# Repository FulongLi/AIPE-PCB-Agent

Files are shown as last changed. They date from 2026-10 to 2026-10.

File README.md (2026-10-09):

# AIPE-PCB-Agent

AI-assisted power-electronics PCB engineering with reproducible KiCad automation.

> **AI-GENERATED ENGINEERING PROTOTYPE — V1 — HUMAN REVIEW REQUIRED**

The first benchmark is a 48 V nominal to 24 V, 1 kW synchronous buck converter
with an integrated TMS320F28335 control section. The output current is
approximately 41.7 A. V1 is a review deliverable, not an energisation approval.

## Current status

The V1 converter CAD is complete on `codex/v1-buck-1kw`: 14 schematic sheets,
240 physical items, a fully routed 300 x 220 mm six-layer PCB, and zero native
ERC/DRC findings. Connectivity, source/export hashes and all eleven export
commands are verified. This establishes a CAD review package, not a validated
1 kW converter. See [execution status](docs/status.md) for freeze and GitHub
handoff state.

- [V1 design report](examples/buck-48v-24v-1kw/review/design_report.md)
- [Schematic PDF](examples/buck-48v-24v-1kw/review/schematic.pdf)
- [PCB layer and assembly PDF](examples/buck-48v-24v-1kw/review/pcb_layout.pdf)
- [Board 3D view](examples/buck-48v-24v-1kw/review/pcb_3d.png)
- [Known issues](examples/buck-48v-24v-1kw/verification/known_issues.md)
- [Verification summary](examples/buck-48v-24v-1kw/verification/verification-summary.json)
- [Reproduction instructions](docs/reproduce-v1.md)
- [Frozen V1](examples/buck-48v-24v-1kw/releases/v1/README.md)
- [Portable V1 review archive](examples/buck-48v-24v-1kw/releases/v1-review-package.zip)

## Engineering Knowledge System (V0)

AIPE now learns from manufacturer reference designs. The
[knowledge base](knowledge/README.md) holds traceable, reusable power-electronics
knowledge extracted from TI TIDA-010054 and Wolfspeed CGD15SG00D2,
CGD1700HB2M-UNA and PRD-04814: six engineering Skills (SiC gate drivers,
gate-driver layout, DC-link capacitors, isolated gate bias, sensing, thermal
placement), 13 circuit building blocks, 19 component records and 43
machine-readable rules — each with evidence locations and an explicit
validation status (reference-derived or analytically checked; nothing is
simulated or hardware-validated yet).

```text
python -m automation.knowledge.query "recommended layout practices for an isolated SiC gate driver"
python -m automation.knowledge.validate
```

- [Architecture and reference-learning workflow](docs/knowledge-system.md)
- [V0 status and findings](docs/knowledge-status.md)
- [Retrieval demonstration](knowledge/examples/retrieval-demo.md)

Raw manufacturer files are downloaded to the Git-ignored `.cache/references/`
by `python -m automation.knowledge.acquire`; only original analysis and
metadata are committed.

## Start here

- [Original task](task071026.txt) and [execution constraints](agents/CODEX_V1_TASK.md)
- [Workflow and acceptance gates](docs/agent-workflow.md)
- [Automation architecture](docs/architecture.md)
- [Installation proposal](docs/installation-plan.md)
- [Host environment](docs/environment.md)
- [PCB engineering rules](docs/pcb-design-rules.md) and [knowledge rules](knowledge/rules/engineering_rules.json)
- [Benchmark requirements](examples/buck-48v-24v-1kw/input/requirements.yaml)

## Environment inspection

From the repository root, using an existing Python 3.10 or newer interpreter:

```text
python -m automation.setup.detect_environment --output .aipe/environment.json --markdown docs/environment.md
python -m unittest discover -s tests -v
```

The detector uses the Python standard library and does not install software.
Machine-specific paths belong in ignored `.aipe/local-tools.json`, using
`automation/setup/local-tools.example.json` as a template. Installing software
or dependencies requires the user's confirmation of both software and location.

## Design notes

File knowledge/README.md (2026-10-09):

# AIPE Engineering Knowledge System — V0

> **Reference-derived engineering knowledge — human review required.** Nothing
> here has been simulated or hardware-validated by AIPE. Status labels say
> exactly how far each item has been checked.

This directory holds reusable power-electronics knowledge extracted from
manufacturer reference designs, in a form both engineers and AIPE agents can
use: Markdown for reasoning, JSON for machine use, and evidence pointers for
every claim. The workflow that produces and checks it is described in
[docs/knowledge-system.md](../docs/knowledge-system.md).

## Contents (V0)

| Area | Location | Count |
|---|---|---|
| Reference records, inventories and analyses | [`references/`](references) | 4 references, 25 documents |
| Engineering Skills (Markdown + JSON index) | [`skills/`](skills) | 6 |
| Circuit building blocks | [`circuit_blocks/`](circuit_blocks) | 13 |
| Component knowledge | [`components/`](components) | 19 |
| Engineering rules | [`rules/engineering_rules.json`](rules/engineering_rules.json) | 43 |
| Evidence checks (recomputed calculations, netlist facts) | [`verification/evidence-checks.json`](verification/evidence-checks.json) | 26 |
| JSON schemas | [`schemas/`](schemas) | 6 |
| Retrieval demonstration | [`examples/retrieval-demo.md`](examples/retrieval-demo.md) | 3 questions |

References: TI [TIDA-010054](references/ti/tida-010054/analysis.md) 10 kW DAB ·
Wolfspeed [CGD15SG00D2](references/wolfspeed/cgd15sg00d2/analysis.md) ·
[CGD1700HB2M-UNA](references/wolfspeed/cgd1700hb2m-una/analysis.md) (with PRD-09301) ·
[PRD-04814](references/wolfspeed/prd-04814/analysis.md) gate-bias options.

Skills: [SKILL-001 SiC gate driver](skills/gate_drivers/SKILL-001-sic-gate-driver-design.md) ·
[SKILL-002 gate-driver layout](skills/pcb_layout/SKILL-002-gate-driver-pcb-layout.md) ·
[SKILL-003 DC-link capacitors](skills/capacitors/SKILL-003-dc-link-capacitors.md) ·
[SKILL-004 isolated gate bias](skills/power_electronics/SKILL-004-isolated-gate-bias-supply.md) ·
[SKILL-005 sensing](skills/sensing/SKILL-005-current-voltage-sensing.md) ·
[SKILL-006 thermal placement](skills/thermal/SKILL-006-thermal-placement.md).

## Layout

```text
knowledge/
  references/<vendor>/<design>/
      reference.json    curated record: documents, URLs, revisions, checksums, licence, limitations
      inventory.json    generated metadata of downloaded files (names, sizes, hashes, formats)
      analysis.md       original AIPE analysis of each design decision
  skills/<domain>/SKILL-NNN-*.md|.json
  circuit_blocks/<category>/CB-XX-NNN.json
  components/<category>/CMP-<part>.json
  rules/engineering_rules.json
  verification/evidence-checks.json
  schemas/*.schema.json
  examples/retrieval-demo.md
```

Raw manufacturer files are downloaded to `.cache/references/` (Git-ignored) and
are never committed.

## Vocabulary

**Validation status** (weakest → strongest). V0 contains only the first two.

| Status | Meaning |
|---|---|
| `reference-derived` | Taken from a manufacturer design or document. An implementation exists; it is not independently verified. |
| `analytically-checked` | The cited arithmetic or connectivity was recomputed by `check_evidence` and agrees with the source. |
| `simulation-verified` | Reproduced in AIPE simulation (none yet). |
| `hardware-validated` | Measured on AIPE hardware (none yet). |

**Evidence kinds:** `stated` (written in the source), `observed` (seen in a
BOM, schematic or layout image), `netlist` (confirmed against CAD netlist data),
`calculated` (recomputed), `inferred` (AIPE interpretation the source does not
state — always flagged).

**Rule categories:** `hard-constraint`, `optimization-objective`,
`engineering-recommendation`, `human-review-requirement`. Rule **generality**:
`single-reference-observation`, `multi-source-consistent`,
`manufacturer-guidance`, `physics-derived`. Policies enforced by the validator:

- a single-reference observation is never a hard constraint;
- `multi-source-consistent` needs evidence from at least two references;
- a hard-constraint numerical limit cannot rest on a design-instance value;
- `analytically-checked` requires at least one cited, passing evidence check;
- conflicting approaches are kept in `conflicts`/`alternatives`, not resolved silently.

## Using the knowledge (agents and engineers)

```text
python -m automation.knowledge.query "recommended layout practices for an isolated SiC gate driver"
python -m automation.knowledge.query "DC-link capacitor selection" --type rule --json
python -m automation.knowledge.query --get CB-GD-001
```

Python API for the future AIPE Orchestrator:

```python
from automation.knowledge.query import KnowledgeBase
kb = KnowledgeBase.load()
hits = kb.search("isolated current sensing for an 800 V bus", types={"block"}, limit=5)
block = kb.get(hits[0]["id"])["record"]        # full JSON record
links = kb.related(hits[0]["id"])              # skills, rules, components, referenced_by
```

Each hit carries `id`, `type`, `validation_status`, `path`, `sources` and a
snippet. Agents should cite ids and evidence locations, respect
`applicability` and `exclusions`, and surface `human-review-requirement` rules
to the reviewer instead of deciding them.

## Extending: adding a new reference design

1. Create `references/<vendor>/<design>/reference.json` with document entries
   (official URL, kind, file name/type, `redistribution: not-verified`).
   Use only manufacturer URLs; never construct or guess links.
2. `python -m automation.knowledge.acquire --reference REF-…` — downloads,
   checks file type, records date, size, SHA-256 and resolved URL.
3. `python -m automation.knowledge.inspect_sources` — inventories archives and
   extracts text/CSV into the cache.
4. Read the material; record revision, licence terms, limitations and source
   discrepancies; write `analysis.md` (seven questions per decision).
5. Add or update skills, blocks, components and rules with evidence pointing to
   document ids and locations. Prefer extending existing items over duplicates.
6. Add evidence checks for any calculation or connectivity you rely on
   (`automation/knowledge/check_evidence.py`), then run it.
7. `python -m automation.knowledge.validate` and
   `python -m unittest discover -s tests`; regenerate the retrieval demo with
   `python -m automation.knowledge.query --demo` if rankings change.

## Known limitations of V0

- Four references; sensing and DC-link knowledge rest mainly on TIDA-010054.
- TI Altium sources were not parsed; TI layout knowledge is visual observation.
- Several capacitor and module datasheets could not be retrieved automatically
  (recorded per component as `unverified` or `not-located`).
- Retrieval is lexical BM25 with a small synonym table, adequate for routing an
  agent to the right items but not semantic search.
- No AIPE simulation or hardware validation; Buck V1 is unaffected.

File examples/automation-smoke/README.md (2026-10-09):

# KiCad automation smoke test

This is a passive 10k/10k divider with a three-pin connector. It is not the
1 kW converter. Sources, reports and outputs demonstrate the CAD pipeline only.

The 25 x 18 mm, two-layer board has three components, three nets, routed top and
bottom tracks, a through via and a filled bottom ground zone. All symbol pins
are connected. Official KiCad symbols and footprints are retained locally as
small library subsets. KiCad's installed 3D library supplies the component models.

## Run

1. Configure the existing KiCad CLI/Python in `.aipe/local-tools.json`.
2. Run `automation/kicad_tools/generate_smoke.py` using KiCad's bundled Python.
3. Run `python -m automation.kicad_tools.run_check erc examples/automation-smoke/kicad/AIPE_Smoke.kicad_sch --output examples/automation-smoke/verification`.
4. Run the same wrapper with `drc` and the `.kicad_pcb` source.
5. Run `python -m automation.kicad_tools.export_outputs examples/automation-smoke/kicad/AIPE_Smoke.kicad_pro --output <fresh-output-directory>`.

The checked-in successful exports are under `outputs/`. Export deliberately
requires a fresh directory so stale files cannot establish a passing run.
`python -m automation.verification.verify_smoke` checks the latest reports,
source hashes, exact three-net connectivity and the recorded export hashes.

## Observed result

KiCad 10.0.7 on Windows: ERC zero findings; DRC zero findings, unconnected items
and schematic-parity issues. No checks were disabled by the generator. The
reports list KiCad's default ignored checks explicitly; no exclusions were added.
Schematic PDF, four-page layer PDF, Gerber, drill, BOM, positions, STEP and
front/back/isometric images exported successfully. The final schematic and four
PCB PDF pages were rendered and visually inspected. STEP includes component
models, confirmed by the board renders. The exported netlist matches all seven
expected component-pin connections exactly.

Early failed runs remain in `verification/` as diagnostic history. The
`smoke-result.json` identifies the passing evidence. This test establishes only
this small pipeline, not the correctness of future converter circuitry or layout.

For non-Windows installations provide `AIPE_KICAD_DATA` if the data directory is
not beside the executable at `../share/kicad`, and use an interpreter that can
import the installed KiCad PCB bindings. Those hosts are not tested yet.

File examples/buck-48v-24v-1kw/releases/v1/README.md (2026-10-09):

# Frozen V1 review prototype

AI-GENERATED ENGINEERING PROTOTYPE - V1 - HUMAN REVIEW REQUIRED

Start with review/design_report.md, review/schematic.pdf and review/pcb_layout.pdf.
Read verification/known_issues.md before any physical work. Sources and exported
manufacturing formats are included, but no fabrication order is authorized.

This snapshot must not be overwritten. Future reviewed changes belong in V2.
SHA256SUMS.json covers every file except itself. Original-host absolute paths
inside native command logs are historical evidence; relative content paths
inside this snapshot remain usable. No private host configuration is included.

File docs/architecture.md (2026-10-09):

# Automation architecture

The repository is the engineering record. Each design input, generated CAD
source and verification output must remain traceable to a commit.

```text
Requirements + documented assumptions
    -> engineering calculations and component evidence
    -> deterministic design description
    -> KiCad schematic and PCB source
    -> real KiCad checks and exports
    -> engineering review and frozen V1 package
```

Python is the cross-platform orchestration language. Prefer `kicad-cli` for
checking and exporting; investigate official IPC/Python interfaces for editing.
Where an operation is unavailable, use the documented KiCad file formats and
validate the generated files with KiCad. No third-party MCP server is required.

The initial setup code uses only the Python standard library. Avoid relying on
shell activation, Unix-only locations, or modifying global Python packages.
Discover tool paths using explicit configuration, environment overrides, PATH,
and conventional platform locations. Record which path was actually used.

The CLI check wrapper must preserve nonzero exit codes, capture logs and reject
missing output reports. A unit test using a simulated process result is only a
test of this wrapper; it is not an ERC/DRC result or a CAD integration test.

The complete operation layer will grow with verified needs: project creation,
schematic connectivity and footprint assignment, board stack-up, placement,
tracks/vias/zones, checks, exports and review images. These are planned
capabilities, not a claim of current implementation.

## Engineering knowledge layer

Design decisions can draw on the reference-derived knowledge base in
`knowledge/` (skills, circuit blocks, component knowledge and rules with
evidence and validation status). It is produced and checked by
`automation/knowledge/` and queried through `automation.knowledge.query`. See
[knowledge-system.md](knowledge-system.md). It informs design and review; it
does not replace the KiCad checks above or human engineering review.

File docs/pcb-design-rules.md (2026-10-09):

# Initial PCB engineering review rules

These rules originate in the task. The V1 checker
`automation/verification/check_power_layout.py` now measures the actual routed
board, checks pad/net mapping and power topology, and guards the intended
ground-plane extent. The machine-readable register is
`automation/verification/pcb_rules.json`. Measurements do not constitute
validated electrical or thermal limits. See the example's
`verification/pcb_rule_review.md` for the separate final review and open issues.

| ID | Requirement | Current review method | Required evidence |
| --- | --- | --- | --- |
| PE-PCB-001 | Minimise MOSFET gate loop | human-review | Gate and return path overlay; rationale for topology and geometry |
| PE-PCB-002 | Put high-frequency input capacitors close to half bridge | human-review | Pad-to-pad current path and capacitor placement |
| PE-PCB-003 | Minimise commutation loop | human-review | Complete loop overlay including layer transitions and return |
| PE-PCB-004 | Kelvin routing for current measurement | human-review | Sense pad takeoff and differential path inspection |
| PE-PCB-005 | Keep feedback away from switching node | human-review | All-layer coupling/return-path inspection |
| PE-PCB-006 | Size high-current copper and vias | human-review | Copper dimensions, via plating assumptions, current/loss and thermal rationale |
| PE-PCB-007 | Separate control from noisy power structures | human-review | Functional placement and ground-return review |
| PE-PCB-008 | Place decoupling next to the relevant IC pins | human-review | Per-supply pin map, capacitor location and return path |

The table describes the electrical acceptance evidence, which remains a human
responsibility. The register marks geometric support as semi-automated for
rules 001, 002, 004-008. Only exact pad/net equality, explicit critical topology,
layer count and the ground-plane extent guard are automatic invariants. A short
distance alone does not establish a suitable gate or commutation loop.

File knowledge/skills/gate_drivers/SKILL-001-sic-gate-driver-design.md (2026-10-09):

# SKILL-001 — SiC gate driver design

Status: **reference-derived** (cited calculations analytically checked) · Domain: gate drivers ·
Index: [`SKILL-001-sic-gate-driver-design.json`](SKILL-001-sic-gate-driver-design.json)

## Purpose

Design the circuit between a PWM signal and a SiC MOSFET gate: isolation,
drive strength, gate levels, turn-on/turn-off resistance, off-state immunity,
overcurrent protection and the controller interface. The output is a
schematic-level gate-driver specification that a PCB agent can place and route
with [SKILL-002](../pcb_layout/SKILL-002-gate-driver-pcb-layout.md).

## Applicable conditions

- SiC MOSFETs (discrete or module) in half bridges, full bridges or single-ended stages.
- Bus voltages within the isolation and working-voltage ratings of the chosen driver IC.
- Floating references (high side, or bridges with several references) that need isolated drive.

## Not applicable / out of scope

- Non-isolated low-voltage drivers (e.g. the 48 V Buck V1 benchmark uses a bootstrap half-bridge driver; this skill does not cover that design).
- GaN HEMT gate drive (different gate limits); IGBT-specific short-circuit strategies beyond DESAT basics.
- Choosing the power semiconductor itself (AIPE Transistor Database scope).

## Engineering principles

1. **Isolate every position.** Wolfspeed recommends an isolated driver for every module switch position, including low sides, for safety, removal of noise paths and ground loops, and modularity (PRD-09301 §1.2). TIDA-010054 uses one isolated driver per discrete switch.
2. **Reference the driver to the Kelvin source.** The gate is controlled relative to the source; a dedicated Kelvin source removes common-source inductance from the gate loop (PRD-09301 §1.1). Rule KR-PCB-003.
3. **Gate levels are device-specific.** Keep rails plus tolerance and transients inside the device's absolute maxima (KR-GD-001). For Wolfspeed Gen-3 the guidance is +15 V and −3 to −4 V with ±5 % rails, maxima +19/−8 V (PRD-04814). Negative turn-off is recommended in half bridges but 0 V can be acceptable after evaluation (KR-GD-005, conflict preserved).
4. **Peak current both ways.** Gate current peaks occur at turn-on *and* turn-off; modules with many dies need several amperes (≈6 A in Wolfspeed's CAB006M12GM3 example, PRD-09301 §1.3).
5. **Independent R_G,ON / R_G,OFF.** Tune turn-on for overshoot/EMI and turn-off for loss and immunity (KR-GD-002). Use split OUTH/OUTL drivers (CB-GD-001) or a steering diode (CB-GD-002).
6. **Off-state immunity.** Parasitic turn-on is driven by C_GD·dv/dt into C_GS; mitigations are a higher capacitance-ratio device, negative bias, lower R_G,OFF and an active Miller clamp whose path to the die is short (PRD-06933; KR-GD-003).
7. **Hardware short-circuit protection.** DESAT with HV blocking diode(s), configurable trip and blanking, soft turn-off and a latched fault (CB-GD-001; KR-PR-001, KR-GD-004, KR-GD-011). ADC-based protection is too slow (PRD-09301 §5.1).
8. **Discharge the gate when unpowered.** Gate–source resistor on the device side of R_G (KR-GD-007).
9. **Robust signalling.** Differential/fibre over cables, single-ended conversion close to the IC, RC filters on all signals, hardware interlock as a last barrier (KR-GD-008, KR-GD-009).

## Design procedure

1. Collect device data: V_GS absolute maxima and recommended levels, Q_G at those levels, C_iss/C_rss (capacitance ratio), R_DS(on)(T), short-circuit withstand time, Kelvin-source availability.
2. Choose isolation: working voltage and insulation class at the switch node → driver IC rating (KR-SN-001 applies to every barrier part).
3. Choose gate rails (KR-GD-001, KR-GD-005) and the bias supply with SKILL-004; run the power budget P = Q_G·f_sw·(V_DD−V_EE) (KR-IS-001).
4. Choose driver IC by peak current, split outputs, Miller clamp, DESAT/soft turn-off, UVLO and isolated analog channel needs. Reference instances: UCC21710-Q1 (both TIDA-010054 and CGD1700HB2M-UNA), UCC23514 (CGD15SG00D2, no protection).
5. Select starting R_G,ON/R_G,OFF from device datasheet dv/dt and switching-energy curves (PRD-09301 §3.2 example: 3 Ω on / 1.3 Ω off for a 25 V/ns limit); plan to tune by double-pulse test.
6. Design DESAT: number and rating of HV diodes (≥ device voltage), bias/divider for the trip V_DS at the target current and temperature, blanking capacitor from measured ringing and risk tolerance. Use the CB-GD-001 formulas (checked in EC-001/EC-002).
7. Add gate discharge resistor, rail decoupling sized for Q_G (CGD1700: 20 µF per rail), Miller clamp connection if used.
8. Define the controller interface: interlock wiring, fault/RDY combination and latching, reset timing, signalling standard and filters (CB-GD-003).
9. Record every value as an instance with its basis; hand off placement constraints to SKILL-002.

## Component selection considerations

- Driver IC: isolation (working voltage, surge, CMTI vs. expected dv/dt), peak source/sink current, split outputs, Miller clamp current, DESAT threshold accuracy (UCC21710-Q1 V_OCTH 0.63–0.77 V), soft turn-off current, UVLO levels matched to the chosen rails, propagation delay and skew.
- DESAT diodes: blocking voltage ≥ device rating (or several in series), fast recovery, low capacitance; creepage of the diode bodies to other nets.
- Gate resistors: pulse-rated parts (Wolfspeed uses 2512 pulse-proof resistors); power from Q_G·ΔV·f_sw.
- Steering diodes (if used): fast Schottky, low inductance package.
- Alternatives named in sources only: drivers with integrated flyback controller (ADuM4138, Si828x) for combined bias (PRD-04814).

## PCB constraints (hand-off to SKILL-002)

KR-PCB-001 (gate/Kelvin adjacent layers), KR-PCB-002 (decoupling in the gate loop),
KR-PCB-003 (no KS-to-power-source tie), KR-PCB-005 (driver adjacent to switch),
KR-ISO-001/002/003 (barriers, creepage, net classes), DESAT routing: short drain
connection, compact low-voltage detection side (PRD-09301 §6.4).

## Verification methods

- Calculations: DESAT trip/blanking (EC-001, EC-002), bias power and f_sw limit (EC-003, EC-004), rail set-points (EC-005 … EC-007).
- Netlist checks: gate path, clamp and DESAT connectivity (EC-022, EC-023, EC-026 pattern).
- Measurements: double-pulse test for R_G tuning; off-state V_GS during complementary switching with an optically isolated probe at the device side of R_G (PRD-09301 §6.1–6.2); short-circuit and UVLO fault injection; open-cable/both-inputs-high interlock tests.

## Known limitations

- Values from the references are instance values (TI 2 Ω, 6.4 V/1 µs; Wolfspeed 1 Ω, 6.7 V/46 ns; CGD15SG00D2 10 Ω).
- No AIPE simulation or hardware test underlies this skill; status is reference-derived with checked arithmetic and connectivity.
- Module-level guidance (PRD-09301) is applied to discrete devices only where the physics is the same; module-specific items (multiple gate pins, paralleling) are not expanded here.

## Source references

- TI TIDA-010054 — [analysis](../../references/ti/tida-010054/analysis.md) decisions 4–5.
- Wolfspeed CGD15SG00D2 — [analysis](../../references/wolfspeed/cgd15sg00d2/analysis.md) decisions 1, 2, 6; PRD-06933.
- Wolfspeed CGD1700HB2M-UNA and PRD-09301 — [analysis](../../references/wolfspeed/cgd1700hb2m-una/analysis.md) decisions 1–4.
- Wolfspeed PRD-04814 — [analysis](../../references/wolfspeed/prd-04814/analysis.md) decisions 1, 6.

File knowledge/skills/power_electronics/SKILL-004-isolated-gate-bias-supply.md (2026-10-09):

# SKILL-004 — Isolated gate bias power supply design

Status: **reference-derived** (cited calculations analytically checked) · Domain: power electronics ·
Index: [`SKILL-004-isolated-gate-bias-supply.json`](SKILL-004-isolated-gate-bias-supply.json)

## Purpose

Choose and design the isolated supply that powers each SiC gate driver: topology,
rail generation (+V/−V around the source), power budget, isolation capacitance,
regulation and input protection.

## Applicable conditions

- Isolated SiC gate drivers needing a floating bipolar (or unipolar) supply per reference potential.
- Regulated low-voltage auxiliary input (12 V in all references) or, for some topologies, the HV bus.

## Not applicable / out of scope

- Bootstrap supplies (TIDA-010054 provides an untested bootstrap option only).
- Auxiliary supplies for controllers and logic (non-isolated).

## Engineering principles

1. **Budget the gate power.** P = Q_G · f_sw · (V_DD − V_EE) per device plus quiescent and shared loads must fit the supply rating at the actual input voltage (KR-IS-001). Worked examples: 118 nC, 18 V, 2 W → f_sw ≤ 940 kHz (EC-003); 1330 nC, 19 V, 2 W → 79 kHz, ~70 kHz with margin (EC-004). TI's TIDA-010054 uses an expression with an extra factor 2 (EC-014) — a recorded conflict; the Wolfspeed form follows from charge moved per cycle.
2. **Minimise isolation capacitance.** Common-mode current i = C_iso·dv/dt flows into the control side (KR-IS-003). The CGD15SG00D2 LLC transformer has 0.68 pF typ. inter-winding capacitance; PRD-04814 rates topologies qualitatively (module/LLC/push-pull low; multi-output flyback high).
3. **Block the common-mode path.** A CM choke at the converter input, close to it, with the input capacitor between choke and converter (KR-IS-002).
4. **Generate rails around the source.** Options: dual-output modules, single output + resistor–Zener split, or LDO post-regulation (CB-IS-001/003/004). The Zener split's negative rail is load dependent (CGD15SG00D2 measures −3.3 V with a 3.9 V Zener).
5. **Regulation to the need.** Unregulated module outputs suit most applications; characterisation and non-standard levels need LDOs with ≥0.3 V headroom (KR-IS-005; PRD-06992 §4.3.4). Changing V_DD shifts DESAT blanking when it is biased from V_DD.
6. **Share only with review.** Same-reference low sides may share a supply with decoupling resistors and a combined budget; TI provided but did not test sharing (KR-IS-004).
7. **Protect the auxiliary input** feeding all bias supplies (KR-PR-003; CB-PR-001).

## Design procedure

1. List switch positions and their reference nodes; group positions that share a reference.
2. For each supply compute required power (KR-IS-001) with margin; note input-voltage-dependent ratings (UCC14141-Q1: 1.5 W only at 10.8–13.2 V).
3. Select topology with the PRD-04814 comparison: module (simplest, certified, low C_iso, costlier), single-channel LLC (very low EMI/C_iso, specialised control — UCC25800), push-pull (small transformer, single rail — SN6501/SN6505, LT3999), flyback (flexible, higher C_iso/EMI — ADuM4138, Si828x integrated), multi-output flyback/bridge (lowest cost, hard layout, cross-regulation).
4. Choose rail generation and levels per SKILL-001/KR-GD-001; compute Zener/LDO operating points at min/max load.
5. Add input CM choke and input capacitor; local output decoupling sized for gate charge.
6. Verify isolation rating and creepage of transformer/module against the insulation requirement; estimate i_CM.
7. Define power-good/UVLO interaction with the driver.

## Component selection considerations

- Modules: RECOM R12P21503D (+15/−3 V, 2 W), Murata MGJ2D122005SC (+20/−5 V, 2 W) — only the named alternatives from sources are recorded (Mornsun QA15115R2, MGJ2D series).
- Integrated-transformer IC module: TI UCC14141-Q1 (+15/−4 V configured; RLIM sets current limit).
- Discrete LLC: TI UCC25800-Q1 + Würth 750319177 transformer.
- Post-regulators: Analog Devices LT3082 (positive, 10 µA SET) and LT3015 (negative) on CGD1700HB2M-UNA -R variants.

## PCB constraints

- Each supply inside its driver's isolated island; transformer/module straddles the barrier with required creepage (slots/notches) (KR-ISO-001, KR-ISO-004).
- CM choke and input capacitor order (KR-IS-002); output capacitors within the gate loop (KR-PCB-002).

## Verification methods

- Calculation: power budget (EC-003/EC-004/EC-014), LDO set-points (EC-005…EC-007), LLC frequency (EC-008).
- Measurement: rail regulation versus load and input (Wolfspeed Figure 5 method), ripple during switching, common-mode current/EMI pre-scan.
- Review: isolation coordination of the bias part; sharing configurations.

## Known limitations

- Module datasheets for R12P21503D and MGJ2D122005SC could not be verified automatically; their parameters come from Wolfspeed documents.
- PRD-04814 comparison is qualitative; no efficiency or C_iso numbers per topology.

## Source references

- PRD-04814 [analysis](../../references/wolfspeed/prd-04814/analysis.md); CGD15SG00D2 [analysis](../../references/wolfspeed/cgd15sg00d2/analysis.md) decisions 3–4; CGD1700HB2M-UNA [analysis](../../references/wolfspeed/cgd1700hb2m-una/analysis.md) decision 5; TIDA-010054 [analysis](../../references/ti/tida-010054/analysis.md) decisions 4, 7, 8.

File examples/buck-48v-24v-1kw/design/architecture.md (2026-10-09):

# V1 electrical architecture

The input feeds a 40 A / 70 V bolt-down fuse, local TVS, 14 bulk capacitors and
eight local high-frequency ceramics. Two 100 V MOSFETs form each half-bridge leg.
A 10 uH inductor and four-terminal 2 mohm shunt feed the output capacitor bank
and M5 output terminal. The return bus connects the output and input returns.

The UCC27211 gate driver has independent gate resistors for each MOSFET. Bootstrap
and VDD bypass parts are immediately adjacent to its pins. A latched enable and
logic gates inhibit both PWM paths on reset or fault. A combinational overlap
inhibit supplements, but does not replace, the DSP dead-band generator.

Auxiliary conversion is 48 V -> LM5164 12 V -> TPS54302 5 V -> TPS767D301
1.9 V and 3.3 V. A transistor enables the I/O rail only after core power-good.
Open-drain rail reset signals and a 5 V supervisor hold XRS low. The core output
uses substantial bulk capacitance; early power-down reset timing must be measured.
The LM5164 has its prescribed COT ripple-injection network, not merely an FB divider.

The TMS320F28335PGFA uses a 30 MHz 3.3 V oscillator on XCLKIN, X1 grounded, X2
unconnected, external JTAG pulldown/pullups, flash-boot straps, per-supply-pin
decoupling, ADC reference capacitors and a 22 kohm ADC bias resistor. TEST1 and
TEST2 remain unconnected. Unused analog inputs go to analog ground; unused
digital pins are explicitly marked unused. A 3.3 V UART header exposes SCI-A.

Vin and Vout are divided and buffered. INA240A1 measures inductor current after
the inductor using true Kelvin shunt terminals. LM61 measures power-area PCB
temperature, not MOSFET junction temperature. Separate comparators implement
overcurrent, output overvoltage, overtemperature, and input undervoltage. Faults
clear the hardware enable latch and reach the DSP trip-zone input. Recovery
requires an explicit arm edge after all faults clear.

The analog and digital grounds are one electrical net with placement-controlled
return paths over continuous planes. There is no split under ADC or PWM tracks.
Switch-node copper and plane exposure are restricted to the power area. Sensor
traces avoid the inductor, switching node and gate loops.

Sources, revisions and download hashes are in `../components/references.json`.
The DSP, driver, regulator and sensor implementations use their manufacturer
pin/function tables. Library symbols and custom pin mappings must be checked
against those tables before the schematic milestone is marked complete.

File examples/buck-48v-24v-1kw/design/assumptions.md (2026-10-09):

# V1 design assumptions

AI-GENERATED ENGINEERING PROTOTYPE - V1 - HUMAN REVIEW REQUIRED

The user supplied 48 V nominal input, 24 V output, 1000 W, synchronous buck,
F28335 preferred, and one integrated PCB. The following are engineering choices,
not additional user requirements.

| Topic | V1 assumption and consequence |
|---|---|
| Input | 36-54 V continuous from a current-limited regulated bench supply; no battery reverse-polarity or automotive surge qualification |
| Output | 24 V / 41.667 A continuous design target; positive-current operation; no prebiased-output start or reverse energy acceptance |
| Frequency | 100 kHz, complementary ePWM1A/B, 200 ns initial dead time |
| Environment | 0-50 C ambient; forced airflow and externally supported insulated MOSFET heatsink required |
| Load behavior | 20 A / 100 us illustrative load step; no guaranteed dynamic specification |
| Board | Final 300 x 220 mm, six copper layers, 2.0 mm total; expanded from the initial 300 x 200 mm estimate for placement/routing |
| Copper | L1/L3/L4/L6 70 um finished copper, L2/L5 35 um; PCB vendor must confirm manufacturability and fine-pitch process |
| Power connection | M5 REDCUBE solder terminals, ring lugs, cable strain relief; 2.2 Nm terminal torque only with mechanical support |
| Main inductor | 285 g part requires a separate mechanical clamp/support; solder joints must not carry shock loads |
| Startup | Controlled supply ramp; input-capacitor inrush is not actively limited on this board |
| Software | Hardware design and firmware interface contract; no energized firmware commissioning or validated closed-loop controller in this task |
| Fault protection | Hardware latch inhibits both gates; not a safety-rated function and not a proven hard-short interruption system |
| Development | No purchases, fabrication or physical power-up; full CAD checks plus human review before any later physical work |

The 36-54 V input range is deliberately recorded here because the original task
specified only the nominal voltage. It is not evidence that the board withstands
arbitrary 48 V-bus transients. Transient suppression and measured switch-node
overshoot require review before fabrication.

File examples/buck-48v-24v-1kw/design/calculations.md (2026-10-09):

# V1 calculation record

Generated by `python -m automation.scripts.calculate_buck`.

These are analytical estimates and explicit design scenarios, not measured performance.

## Operating points

Io = Po/Vo = 41.667 A; D = Vo/Vin; fs = 100 kHz; L = 10 uH.
L scenario minimum = 10 uH x 0.8 tolerance x 0.8 droop = 6.4 uH.

| Vin / V | Duty | Ideal Iin / A | Iin at 95% / A | Ripple nominal / App | Ripple scenario / App | Peak scenario / A | Cin RMS / A |
|---|---|---|---|---|---|---|---|
| 36.000 | 0.667 | 27.778 | 29.240 | 8.000 | 12.500 | 47.917 | 19.732 |
| 48.000 | 0.500 | 20.833 | 21.930 | 12.000 | 18.750 | 51.042 | 20.977 |
| 54.000 | 0.444 | 18.519 | 19.493 | 13.333 | 20.833 | 52.083 | 20.863 |

Ripple: dIL = Vo(1-D)/(L fs); ILrms² = Io² + dIL²/12.
Cin RMS² = Io² D(1-D) + D dIL²/12; Cout RMS = dIL/sqrt(12).

## Capacitors

14 x 470 uF / 100 V EKY-101ELL471MM25S: 6580 uF nominal; 5264 uF at -20%; total rating 24.50 Arms at 105 C / 100 kHz. Maximum calculated RMS is 20.98 A, so sharing must remain within approximately 16% of equal sharing. Matched parts, symmetric buses and measured can temperatures are required.
Input capacitive ripple is 0.020 Vpp near D=0.5; ESR/ESL adds to this. Eight 2.2 uF / 100 V X7R parts provide local commutation bypass; no nominal ceramic capacitance is credited in the bulk calculation because bias derating has not been characterized.
4 x 1000 uF / 50 V EKY-500ELL102ML25S: 4000 uF nominal, 3200 uF at -20%, 10.22 Arms rated. Worst scenario ripple: capacitive 0.008 Vpp plus impedance-based proxy 0.130 Vpp. A 20 A load step for 100 us gives 0.625 V capacitive droop plus ESR response.
The manufacturers specify impedance at 100 kHz, not pure ESR. The loss and voltage terms using that impedance are approximations and cannot establish broadband behavior.

## MOSFET and driver

Two CSD19536KCS in parallel per leg, 100 V rated. At 54 V the static voltage margin is 46 V; ringing must be measured and kept below an 80 V engineering target. Individual 4.7 ohm gate resistors and 10 kohm gate-source pulldowns prevent uncontrolled sharing and floating gates.
UCC27211DDAR runs at 12 V. Upper gate-charge budget is 2 x 153 nC per output. Charge/0.5 V requires 0.612 uF effective bootstrap capacitance. Fit 2.2 uF / 25 V plus 100 nF and require at least 1 uF effective. Driver logic inputs are driven at 3.3 V. Initial dead time is 200 ns at each edge; verify both Vgs waveforms before reducing it.
Gate-drive power upper budget is 4 Qg Vg fs. 100 ns total high-side overlap is assumed; gate resistance, parasitics and Miller charge require double-pulse validation. Bootstrap operation requires a low-side refresh interval and does not permit 100% duty.

## Nominal losses

| Item | W |
|---|---|
| mosfet conduction 4 devices | 4.012 |
| high side overlap 100ns total | 10.000 |
| reverse recovery budget | 1.920 |
| output capacitance budget | 1.608 |
| body diode deadtime 200ns each | 1.500 |
| gate drive upper budget | 0.734 |
| inductor copper 100C | 1.946 |
| inductor core budget unverified | 4.000 |
| shunt 2mohm | 3.496 |
| input capacitor ESR proxy | 1.131 |
| output capacitor ESR proxy | 0.075 |
| copper connections budget | 3.000 |
| fuse budget | 0.750 |
| auxiliary input budget | 4.500 |
| Total | 38.674 |

Estimated efficiency 96.28%; if total loss doubles, 92.82%. This is a scenario range, not an efficiency specification.
Reverse-recovery charge of 200 nC per low-side FET and 4 W inductor core loss are explicit budgeting assumptions. They are not guaranteed part parameters. CSD19536KCS Qrr is characterized at a different current; measured losses can exceed the estimate. Coss/Qoss and recovery budget may overlap; conservative accounting is intentional.

## Sensing and thresholds

Vin: 121 kohm / 4.99 kohm divider => 2.139 V at 54 V. Vout: 49.9 kohm / 4.99 kohm => 2.182 V at 24 V. Buffer voltage channels before the ADC sampling capacitors.
2 mohm four-terminal shunt and INA240A1 gain 20 => 1.667 V at full load. Hardware OCP nominal 60.0 A; OVP 27.5 V; LM61 overtemperature 90.0 C. Comparator and reference tolerances, amplifier offset, shunt heating and dynamic delay must be included in test limits.
At 54 V into a short with 6.4 uH, di/dt is 8.44 A/us. The sensing/comparator chain is not certified short-circuit protection: even 3 us adds 25.3 A. The input fuse limits sustained faults, and a current-limited source is an explicit boundary condition. A fuse does not protect the MOSFET from all fast faults.

## Copper and thermal arithmetic

A 100 mm x 25 mm path using two parallel 70 um copper layers at 100 C is 0.638 mohm, dissipating 1.107 W at 41.67 A. This is resistance only, not an IPC temperature-rise qualification.
A 2 mm long 0.5 mm finished-hole via with assumed 25 um barrel plating is 1.137 mohm at 100 C. 32 in parallel dissipate 0.062 W at full load under equal-sharing assumption. Specify plating to the fabricator and avoid using a small signal-via group for the power path.
DSP rail budgeting: 1.9 V x 0.4 A and 3.3 V x 0.2 A. Dual LDO dissipation 1.58 W from 5 V. Auxiliary 12 V rail budget <0.5 A, below the LM5164 1 A rating; a separate fan supply is required.
LC natural frequency is approximately 795.8 Hz. The digital compensator and transient response remain unvalidated; a firmware interface contract is supplied separately.

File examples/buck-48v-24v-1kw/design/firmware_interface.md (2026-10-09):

# Firmware interface contract - hardware V1

This is a required implementation contract, not working or tested firmware.
Hardware CAD completion does not establish stable closed-loop operation.

| Function | DSP / signal | Required interpretation |
|---|---|---|
| High / low PWM | GPIO0 / GPIO1, pins 5 / 6 | ePWM1A / ePWM1B; active high through enable logic |
| Arm | GPIO2, pin 7 | Rising edge latches enable only while FAULT_N is high |
| Hardware trip | GPIO12 / TZ1, pin 21 | FAULT_N low must asynchronously force both PWM outputs low |
| Vin | ADCINA0, pin 42 | Divider factor 4.99 / 125.99; 54 V -> 2.139 V |
| Vout | ADCINA1, pin 41 | Divider factor 1 / 11; 24 V -> 2.182 V |
| Current | ADCINA2, pin 40 | 0.002 ohm x gain 20 = 40 mV/A; positive current only |
| Temperature | ADCINA3, pin 39 | LM61 nominal 0.6 V + 10 mV/C; local PCB temperature |
| Clock | XCLKIN, pin 105 | External 30 MHz; configure PLL only after clock checks |
| Reset | XRS, pin 80 | External open-drain collection; do not drive push-pull high |
| UART | GPIO29 TX pin 2 / GPIO28 RX pin 141 | 3.3 V SCI-A; no RS232 voltage tolerance |

On reset, keep both PWM commands and ARM low, configure TZ1 as a one-shot
asynchronous trip, and leave gate enable cleared. Check rail stability,
reference calibration, plausible sensor values and acceptable input voltage
before arming. Set flash wait states and clock/PLL settings for the actual
silicon and 1.9 V core; use TI's device documentation.

For a 150 MHz time-base clock with no prescaler, center-aligned up/down counting
at 100 kHz uses TBPRD=750. An initial 200 ns dead-band is 30 TBCLK ticks. This is
only an initial timing choice: establish the real switching delays and avoid
cross-conduction across temperature, current and supply. Never rely on the
combinational XOR/AND network to generate deadtime.

Bootstrap supply requires low-side refresh; do not command 100% high-side duty.
Use a conservative duty ceiling (initial software proposal 0.80) and controlled
soft start. Enable synchronous low-side operation only under a reviewed
positive-current strategy; do not force reverse current into an unqualified
input supply. Prebiased-output startup is not supported by this V1 contract.

ADC sample timing should avoid switching edges. Set an acquisition window that
allows the 100 ohm / 1 nF front-end network and DSP sample capacitance to settle.
The ADC full-scale is 3 V. Calibrate offset/gain, especially shunt current and
temperature; rail clamps are not precision 3 V limiters. Implement lower
software current/temperature limits before the hardware fault thresholds.

A voltage-loop plant model, compensator, current limiting, anti-windup,
load-step behavior and stability margins remain to be developed and reviewed.
The approximately 796 Hz nominal LC resonance does not establish a valid
control bandwidth. No gains are invented in this package.

Any fault must keep PWM outputs low and latch a diagnostic. Do not repeatedly
auto-retry a short. Release requires an explicit reviewed restart sequence and
new ARM edge. Verify reset/enable behavior during brownout, loss of 5 V/12 V,
debugger attach, missing clock and firmware hang before any later power tests.

J8 1-2 sets GPIO84 low (SCI-A boot); J8 2-3 or no jumper selects Flash (1111).
Never connect a 5 V UART or a debugger's supply output to these rails. This task
does not authorize physical connection, fabrication or energization.

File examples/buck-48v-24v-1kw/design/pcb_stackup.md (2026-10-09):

# V1 PCB stack-up and assembly basis

AI-GENERATED ENGINEERING PROTOTYPE - V1 - HUMAN REVIEW REQUIRED

Final outline: 300 x 220 mm, rectangular, eight 3.2 mm NPTH support holes,
2.0 mm nominal total thickness. The board is larger than the initial estimate
to accommodate the input ripple-current bank and power/control separation.

| Order | Layer / dielectric | Thickness | Function |
|---|---|---|---|
| 1 | F.Cu | 70 um | Components, gate escapes, VIN/SW/force/output and ground pours |
| | Prepreg | 0.18 mm | FR4 nominal Er 4.3 |
| 2 | In1.Cu | 35 um | Ground, with window beneath extended SW |
| | Core | 0.30 mm | FR4 |
| 3 | In2.Cu | 70 um | VIN and routed signals |
| | Center prepreg | 0.69 mm | FR4 |
| 4 | In3.Cu | 70 um | Routed signals and localized SW power bridge |
| | Core | 0.30 mm | FR4 |
| 5 | In4.Cu | 35 um | Ground, with window beneath extended SW |
| | Prepreg | 0.18 mm | FR4 |
| 6 | B.Cu | 70 um | Power force/output/SW, signals and ground |

Copper totals 0.35 mm and dielectric totals 1.65 mm. ENIG is the proposed
finish. This is a design stack, not a fabricator quotation. The fabricator must
confirm achievable dielectric thicknesses, finished copper, fine-pitch pad
clearance, solder-mask registration and plated-slot quality.

Ordinary signals are 0.2 mm with 0.2 mm clearance. Default vias are 0.6/0.3 mm
diameter/drill. Minimum checks retain 0.15 mm copper clearance/track width,
0.25 mm drilled-hole separation, and 0.5 mm copper-to-edge clearance. Local
power-zone clearance is 0.5 mm. No meaningful DRC category is disabled.

Main copper transfer at each shunt force terminal uses 32 vias, 1.0 mm diameter,
0.5 mm finished drill, 1.5 mm pitch. The analytical barrel estimate assumes
25 um plating and uniform sharing. It is a resistance/loss estimate, not a
certified current rating. At 41.67 A, the two 32-via arrays must be reviewed
with the shunt-pad bottleneck and hot terminal temperature. Main switch-node
copper uses a third 70 um layer to maintain a continuous power connection
through the gate-routing region.

U1/U2 have five grounded exposed-pad vias each; U4 has nine. Vias under exposed
pads require fabrication/assembly agreement on filling, plugging or tenting to
control solder loss. Ground pours connect directly to pads; large through-hole
power joints will need a qualified soldering process and thermal profile.

## Mechanical and assembly review

- L1 uses two plated 8.5 x 3.0 mm slots at 32.51 mm center spacing. This follows
  the 10 uH Figure B lead geometry, not a generic two-pin inductor. Provide a
  clamp/bracket using the support region; do not rely on solder joints for its
  285 g mass. Its upright envelope is about 55 mm tall.
- R9 uses distinct force and sense pads. Do not bridge the sense pads to force
  copper during footprint cleanup. Orient its two sense terminals toward the
  top of the board as shown in the assembly drawing.
- F1 is a 40 A / 70 V MIDI fuse on 30 mm M6 centers. Its PCB pad/hole geometry
  is a proposal; the insulating support, fasteners, torque and replacement
  clearance require a mechanical drawing and fuse-datasheet review.
- J1-J4 are M5 REDCUBE terminals. Support the terminal during tightening and
  restrain the cable. The vendor's 20 C current rating is conditional on the
  complete PCB/cable assembly and cannot be carried unchanged to hot operation.
- Q1/Q2 tabs are VIN; Q3/Q4 tabs are SW. An external common heatsink requires
  insulating pads and shoulder washers with verified thermal and dielectric
  performance. Clearance for the actual heatsink is not proven by the STEP.
- J7 is a TI 14-pin JTAG header; remove pin 6 or use a keyed equivalent. J8
  jumper 1-2 selects SCI boot; 2-3 or open selects Flash. J9 is 3.3 V UART only.
- Custom L1/R9/F1/U1/U2/U4/Y1 3D shapes are dimensioned envelope models, not
  manufacturer-certified mechanical CAD. Slots/threads, exact lead bends,
  clamps, cables, insulation and heatsinks are not fully modeled. Stock
  capacitor models can also differ in exact height from the selected MPN.

See the F.Fab page in pcb_layout.pdf for designators. Test points are identified
in the schematic and the generated test-point map. Mask and paste outputs are
provided for review; no stencil thickness or final reflow process is specified.

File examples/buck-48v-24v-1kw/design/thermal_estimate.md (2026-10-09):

# V1 thermal estimate and limits

The reproducible loss budget is in calculations.json. It combines manufacturer
maximum DC resistance with clearly identified hot-resistance, switching-time,
reverse-recovery, core-loss and interconnect assumptions. It is not a thermal
simulation or measurement.

Use an external heatsink with total sink-to-air thermal resistance no greater
than 1.5 C/W under its specified forced airflow. Budget 0.5 C/W per isolated
TO-220 interface plus the CSD19536KCS maximum 0.4 C/W junction-to-case. Drain
tabs are electrically live: high-side tabs are VIN; low-side tabs are SW. A
common conductive heatsink requires verified insulating pads and shoulder
washers. Heatsink selection and its mechanical drawing remain review items.

With 25 W spread over the four MOSFETs at 50 C ambient, the sink rise would be
37.5 C and an 8 W hottest device would add about 7.2 C junction-to-sink. This
illustrative 95 C junction estimate excludes airflow obstruction and uneven
sharing; doubling the heat invalidates the assumed margin. Do not rate the
converter for continuous 1 kW from this arithmetic alone.

The inductor copper budget uses DCR at 100 C. The 4 W core-loss allocation needs
manufacturer loss data or measurement at the actual waveform. The shunt
dissipates about 3.5 W; its 6 W rating is conditional on terminal temperature.
Give its force terminals substantial copper without compromising Kelvin sense.

The dual LDO loses about 1.58 W for a 400 mA core / 200 mA I/O budget. Its exposed
pad needs a grounded thermal-via matrix and connected copper on multiple layers.
Actual DSP current depends on clocks and enabled peripherals. Confirm regulator
junction temperature and rail transients with the application firmware.

The input capacitor group has limited ripple-sharing margin. Review hot-spot
can temperature and life with the actual airflow. Copper and via resistance
calculations establish loss estimates only; temperature rise, plated slots,
connector joints, fuse studs and narrow necks require a fabricator/engineer review.

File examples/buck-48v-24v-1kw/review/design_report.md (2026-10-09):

# AIPE 48 V to 24 V / 1 kW - V1 design review

**AI-GENERATED ENGINEERING PROTOTYPE - V1 - HUMAN REVIEW REQUIRED**

V1 is a complete CAD review prototype with a routed integrated power/control
board. It is not a fabrication release, a validated converter, or permission to
energize hardware. No parts were purchased and no hardware was powered.

## Specification and assumptions

The supplied benchmark is a synchronous buck, 48 V nominal input, 24 V output,
1000 W and a preferred TMS320F28335 controller. V1 assumes 36-54 V continuous
input from a current-limited regulated bench source, positive output current,
0-50 C ambient, forced airflow and external insulated heatsinking. Prebiased
startup, reverse energy, battery faults, hotplug and automotive transients are
outside the qualified scope. These are engineering choices, not user-supplied
performance guarantees. See [assumptions](../design/assumptions.md).

## Design and calculations

| Quantity | Design value / interpretation |
|---|---|
| Output current | 41.667 A nominal |
| Input current | 21.93 A at 48 V and an assumed 95% efficiency; 29.24 A at 36 V |
| Switching frequency | 100 kHz, complementary PWM with an initial 200 ns deadtime |
| Duty ratio | 0.444-0.667 ideal over the assumed input range |
| Main inductance | 10 uH; 6.4 uH conservative tolerance-plus-droop scenario |
| Inductor ripple | 12 App nominal; 20.83 App in the 54 V / 6.4 uH scenario |
| Peak current | 52.08 A in that scenario, before fault overshoot |
| Input capacitor bank | 14 x 470 uF / 100 V; 6.58 mF nominal; 24.5 Arms summed rating |
| Output capacitor bank | 4 x 1000 uF / 50 V; 4 mF nominal; 10.22 Arms summed rating |
| Input / output ripple demand | 20.98 Arms input; up to 6.01 Arms output |
| Loss budget | 38.67 W nominal scenario; approximately 96.28% calculated efficiency |
| Sensitivity | Doubling the assumed total loss gives approximately 92.82% efficiency |

[Calculations](../design/calculations.md) and their Python generator expose every
assumption. The 100 ns switching-overlap budget, hot MOSFET resistance factor,
reverse recovery, magnetic core loss and copper loss are estimates. Actual gate
and commutation geometry may produce greater loss. No simulated or measured
efficiency, EMI, loop stability or temperature result is claimed.

## Power stage and component selection

The input M5 terminal feeds a 40 A / 70 V MIDI fuse, SMCJ54A TVS, input bulk bank
and eight 2.2 uF / 100 V ceramic bypass capacitors. Two CSD19536KCS MOSFETs are
paralleled in each half-bridge leg, with individual 4.7 ohm gates and 10 kohm
gate-source resistors. Their 100 V rating leaves 46 V static headroom at 54 V;
switching overshoot and the TVS's pulse conditions still require review.

The Vishay IHXL2000VZEB100M3A inductor feeds a Bourns four-terminal 2 mohm shunt
and the output capacitor bank. The magnetic is rated at 83 A for its specified
temperature-rise and 20% inductance-drop conditions. The shunt dissipates about
3.50 W at full load; its 6 W rating depends on terminal temperature. REDCUBE M5
terminals provide bolted connections, with cable strain relief and support
during torque. The 285 g inductor needs an independent clamp.

[Selection and stress register](../components/component_selection.csv),
[purchasing BOM](../components/bom.csv), and
[manufacturer reference hashes](../components/references.json) are separate
from KiCad's native BOM. There are 220 purchased electronic parts plus twelve
bare test points and eight mounting holes. Hardware, heatsinks, insulation,
cables and the magnetic clamp are not a completed mechanical purchasing BOM.

## Driver, control, sensing and protection

The UCC27211 runs from 12 V with local bootstrap/VDD capacitors. LM5164 generates
12 V using the manufacturer's COT ripple-injection arrangement; TPS54302 then
generates 5 V. TPS767D301 supplies approximately 1.899 V core and 3.3 V I/O.
Core power-good enables the I/O regulator through an NPN stage. Open-drain rail
status and a TPS3808 5 V monitor hold the DSP in reset.

All 176 DSP package pins are explicitly assigned. The design includes a 30 MHz
oscillator, per-supply bypass capacitors, ADC reference capacitors and bias
resistor, reset, flash/SCI boot selection, TI 14-pin JTAG and 3.3 V UART.
GPIO0/1 provide ePWM1A/B, GPIO2 arms the latch, and GPIO12 receives FAULT_N/TZ1.
The [firmware interface contract](../design/firmware_interface.md) defines the
required behavior; no commissioned control-loop firmware is supplied.

INA240A1 senses separate shunt Kelvin terminals. Voltage dividers and LM61
temperature sensing feed TLV9004 buffers, ADC RC networks and rail clamps.
The ADC full-scale range is 0-3 V, not 3.3 V. LM61 measures local board
temperature, not MOSFET junction temperature.

LM2903B comparators collect approximately 60 A overcurrent, 27.5 V overvoltage,
90 C board temperature and 34.5 V input undervoltage faults. Fault/reset/12 V
power-good clear the hardware latch; restart requires a new ARM edge. XOR/AND
logic inhibits simultaneous PWM commands, but does not replace DSP deadtime or
prove freedom from propagation-delay hazards. The INA240/comparator path is
not proven fast enough to save MOSFETs during a hard short. At 54 V / 6.4 uH,
short-circuit current can rise about 8.44 A/us.

## PCB implementation

The 300 x 220 x 2.0 mm board has six copper layers. L1/L3/L4/L6 use 70 um copper;
L2/L5 use 35 um ground planes. Power occupies the upper region, driver and
sensing the middle, and DSP/auxiliary supplies the lower region. The layer
order, material assumptions, drill treatment and assembly constraints are in
[stack-up and assembly notes](../design/pcb_stackup.md).

Routing contains 3491 track segments and 720 through vias. VIN uses F.Cu and
In2.Cu; the main switch node uses F.Cu, In3.Cu and B.Cu. The dedicated inner SW
region connects the power copper across interruptions caused by gate routing.
Inductor/shunt/output force paths use both outer layers. Each side of the
surface-mount shunt has 32 large current-transfer vias. Signals use the two
internal signal layers and the back, with top-layer escapes where necessary.
Ground is one electrical net, with two planes and outer copper pours. Plane
windows reduce overlap beneath the extended switch-node region.

## Separate engineering self-review

The review found and corrected an incompatible first package choice for small
logic, undersized driver/regulator exposed-pad geometry, a bootstrap/SW copper
disconnection, duplicate/closely spaced vias, incomplete JTAG routing, exposed-
pad thermal-via omissions, a boot jumper arrangement that could short the rail,
and overlapping connector silkscreen. A separate layer-image inspection found
and corrected a polygon API indexing error that had made a large unintended
ground-plane cutout despite a passing DRC; an area/window invariant now guards
against recurrence. These corrections were followed by new
native checks. Historical failed reports are retained as development evidence.

The final CAD is connected, but its power layout is not optimized or qualified:
driver-to-gate straight-line distances are 8.74-16.17 mm; the LO branch network
has 59.75 mm total track length. HF capacitor-to-drain pad distances are 11 mm
for the upper devices and 16 mm for the lower devices. Switch-node copper is
approximately 508/606/546 mm2 on F.Cu/In3.Cu/B.Cu. These dimensions warrant
overshoot, gate ringing and EMI review. They are not a minimized-loop claim.

The sense paths are true Kelvin nets but are not length-matched differential
pairs. DSP bypass pad distances range up to 6.86 mm. The input bank has only
about 17% summed ripple-rating margin before unequal sharing and temperature.
The [rule-by-rule review](../verification/pcb_rule_review.md) answers all task
review questions and identifies the limits of automated geometry checks.

## Verification and handoff

KiCad 10.0.7 native ERC and DRC, with all severities and schematic parity,
returned zero findings. DRC reports zero unintentionally unrouted connections.
An independently exported XML netlist matches all 645 assigned pins on 85 named
nets; board pads and footprints match the model. All eleven export commands
completed, and export/source hashes are checked. Six automation-wrapper tests
and the original automation smoke example also pass. See
[verification summary](../verification/verification-summary.json).

The review directory contains schematic/layout PDFs and three board views.
Manufacturing contains six copper Gerbers, masks/paste, silkscreen, outline,
drills, coordinates, BOM and STEP. They are review artifacts, not a released
fabrication order. V1 is frozen with a SHA-256 manifest; it must not be edited
for V2. GitHub upload requires repository write access for the authenticated
account; local completion does not imply a remote branch or PR exists.

Priority human decisions are the switching-loop quality, short-circuit strategy,
thermal/mechanical design, input inrush/ripple life, auxiliary rail sequencing
and closed-loop firmware. Read [known issues](../verification/known_issues.md)
before approving any physical work.

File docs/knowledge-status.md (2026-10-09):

# Engineering Knowledge System V0 — execution status

Recorded 2026-10-09. Branch: `feat/engineering-knowledge-v0`. Host: macOS,
Python 3.9.6 (standard library; no packages installed).

| Milestone | State | Evidence |
|---|---|---|
| Repository inspection, branch | Complete | Existing architecture preserved; new code under `automation/knowledge/`, data under `knowledge/` |
| Reference acquisition | Complete | 25 documents (58.5 MB) from ti.com and wolfspeed.com, all `downloaded` with SHA-256; 13 component datasheets downloaded |
| PRD-04814 located | Complete | Linked from official CGD15SG00D2 and CGD1700HB2M-UNA product pages |
| Inspection | Complete | Archive inventories; PDF text; XLSX→CSV; Allegro netlist (86 nets) and ODB++ connectivity parsed |
| Reference analyses | Complete for V0 | 4 `analysis.md` files, 31 decisions answered with the seven questions |
| Skills | Complete | SKILL-001…006, Markdown + JSON, all `reference-derived` |
| Circuit blocks | Complete | 13 blocks: 7 `analytically-checked`, 6 `reference-derived` |
| Components | Complete | 19 records; datasheet URL status 12 verified-pdf, 3 unverified, 4 not-located |
| Rules | Complete | 43 rules: 11 hard constraints, 2 optimisation objectives, 25 recommendations, 5 human-review; 7 single-reference observations (none hard); conflicts preserved in KR-GD-003/004/005, KR-IS-001 |
| Evidence checks | Passed | 26 checks: 24 pass, 2 computed-for-review, 0 fail (5 netlist checks need the local cache) |
| Validation | Passed | `python -m automation.knowledge.validate`: 0 errors; all 19 part numbers found in the manufacturers' own files |
| Tests | Passed | `python -m unittest discover -s tests`: 41 tests OK (6 existing + 35 new); without the cache: 41 OK, 1 skipped |
| Retrieval demo | Complete | `knowledge/examples/retrieval-demo.md` |
| Buck V1 | Unchanged | Frozen manifest hashes verified by test; no diff against `main` under `examples/buck-48v-24v-1kw` |

## Findings worth human attention

- **Gate-power expression conflict:** TI TIDUES0 Eq.30 uses 2·(V_DD−V_EE)·Q_G·f_s;
  Wolfspeed uses Q_G·f_s·ΔV. Recorded in KR-IS-001 (EC-014).
- **DESAT blanking philosophies differ by >5×** (TI 1 µs vs Wolfspeed ≈46 ns
  + 120 ns deglitch). Recorded in KR-GD-004.
- **TMCS1133:** TI's BOM orderable `TMCS1133B1QDVGR` is not in the current
  datasheet (which lists `TMCS1133B1AQDVGR`), and TI's guide states 1100 VDC
  working voltage versus 1343 VDC reinforced in the 2026 datasheet.
- **Source inconsistencies** are listed per reference (`source_discrepancies`),
  e.g. stale UCC21530 text in TIDUES0F, J15 supply conflict, CGD1700 schematic
  vs 2025 BOM values, PRD-04814 stray paragraph.

## Not done / limitations

- TI Altium binaries not parsed; TI layout knowledge is visual.
- No simulation or hardware validation; nothing is above `analytically-checked`.
- Retrieval is lexical (BM25), not semantic.
- Full AIPE Orchestrator not implemented (only the retrieval API it will call).

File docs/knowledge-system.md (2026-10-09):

# Engineering Knowledge System — architecture and workflow

The knowledge system turns manufacturer reference designs into traceable,
reusable design knowledge for AIPE agents. It sits beside the existing CAD
automation and does not change it:

```text
Requirements ──► calculations ──► schematic/PCB generation ──► KiCad checks ──► review
                       ▲                     ▲                       ▲
                       └──── knowledge/ (skills, blocks, components, rules) ──┘
                                   ▲
              automation/knowledge (acquire → inspect → extract → check → store)
```

## Reference-learning pipeline

```text
Reference discovery      manufacturer product pages → curated reference.json
        ↓
Download                 acquire.py: official URLs only, type check, SHA-256, date, resolved URL
        ↓
Document / CAD inspection inspect_sources.py: safe unzip, format inventory, PDF text, XLSX→CSV;
                         allegro_netlist.py / odb_netlist.py for CAD connectivity
        ↓
Engineering extraction   analysis.md per reference (what/why/problem/applicability/evidence/reuse/verification)
        ↓
Skill / rule / component skills/, circuit_blocks/, components/, rules/ with evidence pointers
extraction
        ↓
Evidence validation      check_evidence.py (recompute calculations, confirm netlist facts)
                         validate.py (schemas, cross-refs, traceability, policies, part numbers)
        ↓
Knowledge storage        Git: original analysis + metadata; .cache/references: raw files (ignored)
        ↓
Retrieval                query.py: BM25 search, get, related; JSON for agents
```

| Stage | Command | Output | Committed? |
|---|---|---|---|
| Download | `python -m automation.knowledge.acquire` | `.cache/references/<ref>/…`, acquisition block per document and datasheet | metadata only |
| Inspect | `python -m automation.knowledge.inspect_sources` | `inventory.json`; cache `extracted/`, `text/` | inventory only |
| Check | `python -m automation.knowledge.check_evidence` | `knowledge/verification/evidence-checks.json` | yes |
| Validate | `python -m automation.knowledge.validate` | report (exit 1 on any error) | no |
| Retrieve | `python -m automation.knowledge.query …` | ranked hits / JSON | demo file only |

Every reference document records: source URL, document revision and the basis
for that revision, download date, file type, download status, size and
SHA-256, extraction status and method, redistribution status and limitations.
A failed download is recorded as `failed` with the error; it is never shown as
acquired. Checks that need cached files report `skipped` when the cache is
missing — never `pass`.

## Licensing and redistribution

TI design files are bundled with TI's Important Notice, which permits use only
for developing applications with the TI products and prohibits other
reproduction. Wolfspeed documents are "All rights reserved" without a
redistribution licence. Therefore only original AIPE analysis, derived
knowledge, file inventories, checksums and links are committed. The tests
fail if PDF, ZIP, XLSX, STEP or CAD source files appear under `knowledge/`.

## Environment

Standard-library Python (tested here with Python 3.9.6 on macOS; the existing
automation targets 3.10+). Optional, used only when present: `pypdf` for PDF
text, otherwise macOS PDFKit through `osascript`, otherwise documents are marked
for manual reading. `jsonschema` is used only by a cross-check test. No package
was installed for this work.

## Integration points

- **AIPE Orchestrator (future):** `KnowledgeBase.load()`, `.search()`, `.get()`,
  `.related()` in `automation/knowledge/query.py`; or the CLI with `--json`.
  The Orchestrator is not implemented in V0.
- **Existing PCB review rules:** knowledge rules link to `PE-PCB-001…008`
  (`docs/pcb-design-rules.md`) through `related.project_rules`; the validator
  rejects unknown project rule ids. Several rules carry an `aipe_hook` naming
  the automated check they could become (e.g. net-class clearances, Kelvin-net
  separation).
- **Component databases:** component records are design knowledge, not a
  parametric catalogue. `external_refs.aipe_component_db` and
  `external_refs.aipe_transistor_db` are the join keys for the existing AIPE
  databases (null until linked). Power semiconductors (e.g. C3M0075120K) are
  deliberately not duplicated; they appear only as reference usage.

## Validation status of this V0

See [knowledge-status.md](knowledge-status.md) for the recorded results.

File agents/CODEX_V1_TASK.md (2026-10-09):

# V1 execution contract

The user authorised execution of [task071026.txt](../task071026.txt) on
2026-10-09 (Asia/Shanghai), with the following overriding constraint:

> Confirm required software and its installation location with the user before installing.

This includes additional Python packages and automation dependencies. Existing
software may be used. KiCad 10.0.7 x64 and its official libraries are approved for
`D:\EngineeringTools\KiCad\10.0` by the user's subsequent "可以" reply. No other
package installation or dependency upgrade is authorised. Capture approvals in
the installation plan.

Work in `FulongLi/AIPE-PCB-Agent`, branch `codex/v1-buck-1kw`; preserve existing
content. Do not fork or create another repository to bypass missing write access.
The initial remote commit is `c08c1494f5ea9def80efa3f1cbfaac64defdba4a`.

The original task defines scope and outputs. Progress is tracked in
`docs/status.md`. Missing tools and permission failures must be described as
blockers, never reported as successful verification.

Complete a real KiCad smoke test before converter engineering. Do not disable
meaningful ERC/DRC checks. Do not manufacture or energise hardware. Stop the
design sequence after a frozen V1 ready for human review; V2 needs feedback.

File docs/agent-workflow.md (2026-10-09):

# Workflow and acceptance gates

## 0. Environment and smoke test

Inspect host and repository without overwriting collaborator work. Confirm
software and installation paths before installing. Discover and record the real
KiCad executables. Then generate a small, disposable, fully connected test
circuit and board using the automation layer.

Acceptance requires actual KiCad parsing, ERC, DRC (including unrouted items and
schematic parity), schematic PDF, board PDF, Gerber and drill exports. Record
commands, versions, exit codes and nonempty artifacts. Fix issues and rerun.
Library checks must use the installed or project-local symbol/footprint tables.
The converter work remains gated until this succeeds.

## 1. Requirements and engineering

Translate the task into explicit SI-unit inputs and a separate assumption
register. Unspecified limits must not masquerade as user requirements.
Resolve input range, operating temperature/cooling, ripple and transient targets,
mechanical constraints, manufacturing capabilities and control/firmware scope.
Use documented engineering judgement for routine decisions.

Produce reproducible calculations, component stress/loss estimates, protection
thresholds, thermal assumptions and manufacturer references. Document uncertainty
instead of substituting invented ratings or untested operating claims.

## 2. Schematic and board

Complete power, auxiliary supply, DSP, sensing, protection, clock, reset and
debug circuitry. Assign verified footprints, run ERC and correct violations.
Define a justified stack-up; place, route and inspect all intended connections.
Run DRC, schematic parity, footprint and connectivity checks. Treat CAD errors
as release blockers. Document any warning disposition individually.

## 3. Engineering review and release

Apply `pcb-design-rules.md` independently of CAD checks. Each rule needs evidence
and a truthful result: pass, fail, unverified or not applicable with justification.
Unverified engineering constraints must remain visible to the human reviewer.

Export the required manufacturing files and review package. Check the rendered
schematic and board views, reconcile BOM and placement files, then freeze V1
under `examples/buck-48v-24v-1kw/releases/v1/` with a file/hash manifest.
Never call a partial board a completed V1. Never rewrite a frozen V1 later.

Commit meaningful checkpoints and push to the existing remote when authorised
credentials permit. Open the requested PR only when its actual status can be
described accurately. No physical power-up and no V2 without human feedback.

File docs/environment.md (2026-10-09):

# Host environment

Observed (UTC): 2026-10-09T03:20:14.295780+00:00

This report is generated by `automation.setup.detect_environment`.
It inspects the host and does not install software.

| Item | Observation |
| --- | --- |
| Operating system | Windows 10.0.26300 |
| Architecture | AMD64 |
| CPU | Intel64 Family 6 Model 183 Stepping 1, GenuineIntel |
| Python | 3.10.11 |
| Workspace writable | True |
| PATH entries inspected | 29 |
| git | git version 2.53.0.windows.2 |
| gh | gh version 2.88.1 (2026-03-12) https://github.com/cli/cli/releases/tag/v2.88.1 |
| winget | v1.29.380 |
| choco | not found |
| scoop | not found |
| KiCad CLI | D:\EngineeringTools\KiCad\10.0\bin\kicad-cli.exe |
| KiCad Python | D:\EngineeringTools\KiCad\10.0\bin\python.exe |
| KiCad IPC | unverified; no running API connection tested |

## Inspection boundaries

Local executable paths are retained in ignored `.aipe/environment.json`.
A custom KiCad location must be supplied in `.aipe/local-tools.json` or
`AIPE_KICAD_CLI`; discovery is not a scan of every disk.

KiCad plugin directories observed: 1.
MCP inspection records only explicitly declared names, not credentials or
remote plugin-managed servers. The project does not require a KiCad MCP.

```json
{
  "codex_declared_server_names": [
    "cua_repl"
  ],
  "scope": "Local declarations only; does not establish live server availability"
}
```

Actual KiCad file parsing, ERC, DRC, exports and IPC remain unverified until
the integration smoke test has run. Software installation is subject to the
user's separate confirmation of software and directory.

## KiCad version probe

```json
{
  "returncode": 0,
  "output": "10.0.7"
}
```

## KiCad Python probe

```json
{
  "returncode": 0,
  "output": "3.11.5 (main, Aug 30 2026, 05:41:23) [MSC v.1951 64 bit (AMD64)]\n10.0.7"
}
```

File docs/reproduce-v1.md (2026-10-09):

# Reproducing and checking V1

Use Python 3.10+ for standard-library automation and KiCad 10.0.7 with its
`pcbnew` Python environment and NumPy for board generation/routing. No external
autorouter, MCP service, mouse automation or cloud CAD service is required.
The Windows installation and exact detected paths are documented in
environment.md. On macOS, configure paths to the corresponding installed
KiCad CLI/Python environment; generation has not been executed there.

Machine paths are read from `.aipe/local-tools.json`, explicit environment
configuration or the discovery search. A future install still requires user
approval of software and location. Do not include personal tool paths in Git.

## Inspect without changing the frozen release

Open `examples/buck-48v-24v-1kw/kicad/AIPE_Buck_1kW.kicad_pro` in KiCad.
Symbols, footprint tables, custom footprints and envelope models are project
relative. Standard 3D models use the installed KiCad 10 model directory.
Frozen STEP and review renders do not require those model files to view.

From the repository root:

```text
python -m unittest discover -s tests -v
python -m automation.verification.verify_smoke
python -m automation.verification.verify_buck
```

The converter verifier requires source/dependency hashes, native zero-finding
reports, XML netlist equivalence, six copper Gerbers, export file hashes and a
STEP log without missing-model messages. It does not qualify electrical or
thermal performance. Paths recorded in historical command logs describe the
original host; the verifier resolves source and output paths relative to the
repository.

## Regenerate development sources

These operations replace generated development files. Preserve manual edits
first and do not target `releases/v1`. Run board scripts with the KiCad Python
executable rather than a Python interpreter that cannot import pcbnew.

```text
python -m automation.scripts.calculate_buck
python -m automation.kicad_tools.generate_buck_schematic
python -m automation.scripts.component_records
<kicad-python> automation/kicad_tools/generate_buck_board.py
<kicad-python> automation/kicad_tools/route_buck.py
python -m automation.kicad_tools.run_check erc examples/buck-48v-24v-1kw/kicad/AIPE_Buck_1kW.kicad_sch --output examples/buck-48v-24v-1kw/verification
python -m automation.kicad_tools.run_check drc examples/buck-48v-24v-1kw/kicad/AIPE_Buck_1kW.kicad_pcb --output examples/buck-48v-24v-1kw/verification
<kicad-python> automation/verification/check_power_layout.py
```

Use `export_outputs` with a **fresh output directory**, then assemble the review
package after placing the verified export under manufacturing. Required layer
list: `F.Cu,In1.Cu,In2.Cu,In3.Cu,In4.Cu,B.Cu,F.SilkS,B.SilkS,F.Fab,Edge.Cuts`.
Pass `--pdf-scale 0.9` for this A3 board drawing so it clears the title block.
The exporter adds paste and mask layers and records every command and hash.

The current router uses a 0.25 mm grid, conservative obstacle expansion,
alternating DSP fanout, dedicated gate routing, internal signal routing and
explicit power copper. Geometric proposal generation is followed by official
KiCad zone fill and native checks. UUIDs and route details can vary across
KiCad/library versions, so byte-for-byte reproduction on another version is
not promised. Never reuse an older passing report after editing a child sheet,
footprint, project rule, model or board.

No control-loop firmware is generated. Review the hardware/firmware contract
before writing or running any later converter software.

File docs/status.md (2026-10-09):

# Execution status

Recorded 2026-10-09, Asia/Shanghai. Branch: `codex/v1-buck-1kw`.

| Milestone | State | Evidence |
|---|---|---|
| Preserve existing repository | Complete | Original README and c08c149 history retained |
| Environment and approved installation | Complete | KiCad 10.0.7 x64 at D:/EngineeringTools/KiCad/10.0 |
| Reusable automation smoke | Passed | Real ERC/DRC, netlist and eleven exports |
| Calculations and component records | Complete for V1 review | Explicit assumptions; real MPN BOM and stress register; sourcing limitations recorded |
| Schematic | Complete | Fourteen sheets, 240 physical items, all 176 DSP pins mapped |
| Placement and routing | Complete | Six layers, 300 x 220 mm, 3491 segments, 720 vias |
| Native verification | Passed | Final ERC/DRC zero findings; zero unrouted or schematic-parity findings |
| Netlist and artifact checks | Passed | 645 assigned pins, 85 named nets; board/source/export hashes |
| Engineering and visual review | Complete for V1 review | Ground-plane cutout fixed after image review; open electrical/thermal issues explicitly listed |
| Manufacturing and review outputs | Complete | Gerber, drill, BOM, placement, STEP, fourteen-page schematic and eight-page PCB PDFs, three renders |
| Frozen V1 | Complete locally | 155 files under releases/v1, SHA-256 manifest, plus v1-review-package.zip; source commit 7565481 |
| GitHub push / PR | Blocked by repository permissions | Actual push rejected with HTTP 403; authenticated MrCoconut616: pull=true, push=false; prepared body in v1-pull-request.md |

The next phase is human power-electronics review. No hardware qualification,
fabrication, purchase, physical power-up or V2 redesign was performed.

## Remaining external action

Grant the authenticated account write access to `FulongLi/AIPE-PCB-Agent`, or
provide an already authorized repository authentication context. This is a
GitHub repository permission blocker, not a software-installation request.
No separate repository or unauthorized fork was created.

The completed release was committed as `0e70560`. Running
`git push -u origin codex/v1-buck-1kw` returned:

```text
remote: Permission to FulongLi/AIPE-PCB-Agent.git denied to MrCoconut616.
fatal: unable to access 'https://github.com/FulongLi/AIPE-PCB-Agent.git/': The requested URL returned error: 403
```

No remote branch or pull request was created. Once access is granted, push the
existing branch and open the PR against `main` using `docs/v1-pull-request.md`.
The frozen manifest, disk files, Git blobs and portable ZIP were checked for
byte consistency. Its KiCad default display-state file is retained in Git to
match the immutable snapshot; it contains no credentials or host paths.

## Validation scope

Six automation tests pass. Native checks use the real KiCad 10.0.7 tools with
all severities and schematic parity enabled. Ground-plane extent, component
count, pad-net mapping and critical power/control connections have executable
checks. Gate-loop, EMI, thermal, fault-response and control-loop adequacy still
need engineering review. Windows execution is proven here; macOS/Linux tool
discovery paths are implemented but were not executed on those operating systems.

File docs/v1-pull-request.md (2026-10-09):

# AI-generated 48V to 24V 1kW Synchronous Buck - V1

This adds the first complete integrated power/DSP CAD benchmark: a 48 V nominal
to 24 V / 1 kW synchronous buck using TMS320F28335, documented 36-54 V bench-input
assumptions, real component selection, fourteen schematic sheets and a fully
routed six-layer 300 x 220 mm board. Deterministic Python/KiCad automation,
manufacturer references, calculations, review PDFs/renders and manufacturing
formats are included with a frozen V1 checksum manifest.

Validation: KiCad 10.0.7 ERC/DRC with all severities and schematic parity return
zero findings and no unrouted connections. The exported netlist matches 645
assigned pins on 85 named nets; all 240 physical items have matched footprints
and net assignments. All eleven exports and their hashes pass verification.
Six wrapper tests and the real smoke example pass. Layer-image review also
found and fixed a ground-plane geometry problem that DRC alone did not catch.

**AI-GENERATED ENGINEERING PROTOTYPE - V1 - HUMAN REVIEW REQUIRED.** The package
does not establish fabrication/energization readiness. Review priorities are
gate/commutation geometry, hard-short trip delay, input-capacitor ripple/inrush,
thermal and mechanical assembly, rail sequencing, and the as-yet unvalidated
firmware/control loop. See `review/design_report.md` and
`verification/known_issues.md` in the example. No V2 or physical power-up is
part of this PR.

Target: `codex/v1-buck-1kw` -> `main` in `FulongLi/AIPE-PCB-Agent`.
This file is the prepared PR body; it is not evidence that a remote PR exists.

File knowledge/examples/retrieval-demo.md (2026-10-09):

# Knowledge retrieval demonstration

Generated by `python -m automation.knowledge.query --demo`. Deterministic: rerunning on an
unchanged knowledge base reproduces this file. Scores are BM25 relevance, not confidence.

## What are the recommended layout practices for an isolated SiC gate driver?

| Rank | Id | Type | Title | Status | Score |
|---|---|---|---|---|---|
| 1 | `SKILL-002` | skill | Gate driver PCB layout | reference-derived | 20.121 |
| 2 | `SKILL-001` | skill | SiC gate driver design | reference-derived | 17.56 |
| 3 | `KR-PCB-003` | rule | Never tie the device Kelvin source to the power source in the layout | reference-derived | 14.779 |
| 4 | `KR-GD-007` | rule | Gate-source discharge resistor on the device side of R_G | analytically-checked | 12.121 |
| 5 | `KR-PCB-002` | rule | Gate-driver decoupling inside the gate loop | reference-derived | 11.535 |
| 6 | `KR-IS-004` | rule | Sharing a gate-bias supply requires review | reference-derived | 11.39 |

## What should be considered when selecting DC-link capacitors?

| Rank | Id | Type | Title | Status | Score |
|---|---|---|---|---|---|
| 1 | `SKILL-003` | skill | DC-link capacitor selection and placement | reference-derived | 15.672 |
| 2 | `REF-TI-TIDA-010054` | reference | TIDA-010054 bidirectional dual-active-bridge reference design for level 3 EV charging stations | reference-derived | 7.98 |
| 3 | `KR-CAP-002` | rule | DC-link RMS ripple current within rating at frequency and temperature | reference-derived | 6.985 |
| 4 | `KR-CAP-001` | rule | DC-link capacitance from worst-case ripple charge | analytically-checked | 6.527 |
| 5 | `CMP-B32716H8306K000` | component | TDK (EPCOS) B32716H8306K000 | - | 6.006 |
| 6 | `CMP-B32716H1156K000` | component | TDK (EPCOS) B32716H1156K000 | - | 5.913 |

## What reusable current-sensing circuits are available for a high-voltage converter?

Filter: types = ['block']

| Rank | Id | Type | Title | Status | Score |
|---|---|---|---|---|---|
| 1 | `CB-SN-003` | block | Isolated shunt current sensing (isolated amplifier or delta-sigma modulator) | analytically-checked | 6.292 |
| 2 | `CB-SN-001` | block | Isolated HV bus voltage sensing with resistor ladder and isolated amplifier | analytically-checked | 5.327 |
| 3 | `CB-SN-002` | block | Isolated HV voltage sensing with delta-sigma modulator and MCU SDFM | analytically-checked | 4.587 |
| 4 | `CB-SN-004` | block | Hall-effect tank/switch-node current sensing with built-in overcurrent flag | reference-derived | 3.63 |
| 5 | `CB-IS-002` | block | Integrated isolated bias module (+15/-4 V) with optional sensing supply | reference-derived | 3.147 |
| 6 | `CB-PR-002` | block | Isolated thermistor feedback through gate-driver analog-to-PWM channel | reference-derived | 2.29 |

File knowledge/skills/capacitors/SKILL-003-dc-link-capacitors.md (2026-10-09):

# SKILL-003 — DC-link capacitor selection and placement

Status: **reference-derived** (cited calculations analytically checked) · Domain: capacitors ·
Index: [`SKILL-003-dc-link-capacitors.json`](SKILL-003-dc-link-capacitors.json)

## Purpose

Select DC-link capacitance, technology and placement for SiC bridges so that
voltage ripple, ripple-current heating and high-frequency commutation-loop
inductance meet the design targets, and size series DC-blocking capacitors in
transformer-coupled bridges.

## Applicable conditions

- Voltage-source bridges (DAB, PSFB, half/full bridges, inverters) with switched DC-link current.
- DC links of hundreds of volts with switching frequencies in the tens to hundreds of kHz (TIDA-010054: 500/800 V, 100 kHz).

## Not applicable / out of scope

- Line-frequency energy storage and hold-up sizing (e.g. PFC bulk capacitors for 2·f_line ripple).
- Low-voltage converter output filters where ripple is set by an inductor current (the 48 V Buck V1 uses a different method).
- Capacitor lifetime modelling (not covered by the references).

## Engineering principles

1. **Charge balance sets capacitance.** C ≥ ΔQ/ΔV with ΔQ the largest ripple charge over every operating corner (KR-CAP-001). In TIDA-010054 ΔQ rises from 12 µC at nominal to 50 µC at low output voltage; with 5 V ripple this needs ≥10 µF (EC-012), and TI fitted 60 µF.
2. **RMS current sets technology and count.** Ripple current at f_sw heats the capacitor via ESR; low-ESR film is chosen for 100 kHz ripple (KR-CAP-002). Compute I_C,rms over the envelope (TIDUES0 Eq.19 for DAB).
3. **Two tiers.** Bulk film for energy/ripple plus distributed HV ceramics immediately beside each half-bridge for the HF commutation loop (KR-CAP-003, single-reference observation; links to PE-PCB-002).
4. **Voltage rating with margin.** TIDA-010054 uses 1.1 kV film and 1 kV ceramics on the 800 V side, 800 V film and 630 V ceramics on the 500 V side; TI does not state a derating rule, so AIPE does not derive one.
5. **DC-blocking in transformer bridges.** A series capacitor prevents flux walking from volt-second imbalance; size it so the series resonance with the tank inductance is a decade below f_s: C ≥ 100/(4π²f_s²L) (KR-CAP-004; EC-013), rated for full transformer RMS current.
6. **Ceramic DC-bias effect (AIPE caution).** X7R/X7T HV ceramics lose capacitance under DC bias; use manufacturer bias curves before counting them as bulk capacitance.

## Design procedure

1. Define the operating envelope (input/output voltages, power, modulation modes such as SPS/EPS).
2. Simulate or compute the DC-link capacitor current waveform at every corner; integrate for ΔQ; compute I_C,rms.
3. Required C = max(ΔQ)/ΔV_allowed; select film capacitors meeting C, voltage and RMS current at f_sw and maximum temperature; split into parallel parts for current sharing and layout.
4. Add HV ceramics in columns beside each bridge leg; check their effective capacitance at bias and their voltage rating.
5. For transformer-coupled bridges, size the DC-blocking capacitor (C_min, RMS current, voltage).
6. Hand placement to SKILL-002/SKILL-006: ceramics at the switch legs, film close to the bridge with low-inductance connections, thermal environment of film capacitors away from heat-sink exhaust.

## Component selection considerations

- Film: TDK B32716H1156K000 (15 µF, 1.1 kV) and B32716H8306K000 (30 µF, 800 V) in TIDA-010054 — datasheets not retrievable automatically; obtain ripple-current and ESR curves before reuse.
- HV MLCC: Knowles 2220Y1K00474KETWS2 (0.47 µF, 1 kV), TDK CGA9P1X7T2J474M250KC (0.47 µF, 630 V), KEMET C1812V104KDRACTU (0.1 µF, 1 kV).
- Prefer automotive-grade (AEC-Q200) ceramics where vibration/thermal cycling matters (all TI ceramics above are AEC-Q200).

## PCB constraints

- Ceramics adjacent to the switch pins; minimise loop to the opposite rail (KR-PCB-004, PE-PCB-002/003).
- Film capacitors with short, wide, multilayer connections (KR-PCB-006).
- HV creepage around film-capacitor leads and between DC-link polarities (KR-ISO-002).

## Verification methods

- Calculation: ΔQ→C (EC-012), DC-blocking C_min (EC-013), I_C,rms vs rating.
- Simulation: capacitor current at all corners; switch-node waveform with DC-blocking capacitor.
- Measurement: DC-link ripple voltage, capacitor case temperature, V_DS overshoot (commutation loop).

## Known limitations

- Based on one reference design (TIDA-010054) plus general practice; the two-tier placement rule is a single-reference observation.
- Film capacitor datasheets were not acquired; ripple ratings are not recorded.

## Source references

- TIDA-010054 [analysis](../../references/ti/tida-010054/analysis.md) decisions 2–3; TIDUES0 §2.3.4.5; BOM TIDRZW1; layer plots TIDRZW3.

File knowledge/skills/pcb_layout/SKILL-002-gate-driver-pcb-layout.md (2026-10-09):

# SKILL-002 — Gate driver PCB layout

Status: **reference-derived** (cited calculations analytically checked) (manufacturer guidance + observed layouts; net classes netlist-checked) ·
Domain: PCB layout · Index: [`SKILL-002-gate-driver-pcb-layout.json`](SKILL-002-gate-driver-pcb-layout.json)

## Purpose

Turn a gate-driver schematic (SKILL-001) into placement, stack-up, routing and
isolation constraints a KiCad agent can apply and a reviewer can verify:
low-inductance gate loops, intact isolation barriers, correct creepage and
noise-immune signal routing.

## Applicable conditions

- Isolated gate drivers for SiC MOSFETs on multilayer PCBs (4 layers in all three reference boards).
- Drivers integrated on the power board (TIDA-010054) or on plug-in driver boards (CGD15SG00D2, CGD1700HB2M-UNA).

## Not applicable / out of scope

- Power-stage busbar or laminated-bus design (PRD-09301 notes ~200 kW+ systems typically separate drivers from the power stage).
- Numeric creepage/clearance values: these come from the applicable standard, not from this skill.

## Engineering principles

1. **Power loop first, gate loop second.** The commutation loop dominates overshoot; never compromise it for driver routing (KR-PCB-004, PE-PCB-003).
2. **Flux cancellation in the gate loop.** Route gate and Kelvin source as wide pours on adjacent layers; put the Kelvin-source layer between the gate and other circuitry as a shield (KR-PCB-001; PRD-09301 §2.2–2.3). Wolfspeed calls this the most influential gate-inductance measure.
3. **Compact loop includes the decoupling.** The high-frequency gate current closes through the driver's rail capacitors; place them between IC and output pins (KR-PCB-002). CGD15SG00D2 places source-referenced capacitors at the source output pin; CGD1700HB2M-UNA uses 20 µF per rail close to IC and output.
4. **Short distance to the device.** Driver beside its switch (TIDA-010054: drivers on the bottom side next to each TO-247-4); plug-in boards mate directly at the gate/source pins; connectors often dominate inductance (KR-PCB-005).
5. **Isolation barriers are copper-free on every layer.** Separate control side, each driver channel, and the HV side; only barrier-rated parts cross (KR-ISO-001). Plane partitioning on CGD15SG00D2: PGND under LV side and SOURCE under HV side (inner 1); VCC primary and VDD/VSS secondary planes (inner 2).
6. **Net classes by potential.** Group nets (control/primary, low-side channel, high-side channel, DESAT midpoint, drain) and give each class pair a clearance rule (KR-ISO-003; Allegro classes confirmed in EC-024).
7. **Creepage by geometry.** Slots/cut-outs extend creepage where clearance is adequate (KR-ISO-004); DESAT diodes keep full HV distance to other groups.
8. **Noise-immune signals.** Differential pairs adjacent; single-ended segment after the receiver short; RC filters at receiving pins (KR-GD-008).

## Design procedure

1. From the schematic, assign every net to a spacing class (control, per-channel isolated, DESAT midpoint, drain/HV). Create KiCad net classes and class-pair clearance rules from the governing standard (KR-ISO-002, KR-ISO-003).
2. Define stack-up so each driver channel has a gate layer with its Kelvin-source pour on the adjacent layer, Kelvin layer facing other circuitry.
3. Place the power stage and its HF capacitors first (SKILL-003), then each driver IC at its switch, rail capacitors between IC and gate/source pins, gate resistors and discharge resistor at the device end (KR-GD-007).
4. Place the isolated bias supply for each channel inside its island, with the input CM choke and input capacitor on the primary side close to the converter (KR-IS-002).
5. Draw isolation keep-outs per barrier on all layers; add slots where creepage-limited.
6. Route DESAT: drain connection short and direct; long runs only on the HV-diode side; detection resistor/capacitor compact and shielded (PRD-09301 §6.4).
7. Route PWM/fault: differential pairs to the receiver, short single-ended links to IC inputs, filters at the IC.
8. Provide a V_GS measurement point at the device side of R_G (MMCX on CGD1700HB2M-UNA) and drain-sense attachment points.
9. Run DRC with the class rules; inspect each copper layer image for barrier violations; record gate-loop dimensions for review.

## Component selection considerations

- Gate resistors and rail capacitors in packages that keep the loop compact (2512 pulse resistors on CGD1700, MELF 0207 on CGD15SG00D2).
- Connector inductance for plug-in drivers; MMCX probe connectors for V_GS fidelity.
- Bias modules/transformers whose pin spacing supports the required creepage (e.g. transformer notches to 8 mm on CGD15SG00D2).

## PCB constraints

KR-PCB-001 … KR-PCB-005, KR-ISO-001 … KR-ISO-004, KR-IS-002; existing project rules
PE-PCB-001, PE-PCB-007, PE-PCB-008 (docs/pcb-design-rules.md).

## Verification methods

- Automated: KiCad DRC with net-class clearances; netlist check that Kelvin-source and power-source nets are distinct (KR-PCB-003 hook).
- Semi-automated: extract driver-to-device distance and decoupling-loop size (extension of `automation/verification/check_power_layout.py`).
- Human review: per-layer images across every barrier; stack-up adjacency of gate/Kelvin pours.
- Measurement: V_GS ringing with an isolated probe at the device; common-mode noise on PWM/fault lines.

## Known limitations

- TI layout observations are visual (layer plots), not net-verified; the TI design guide contains no layout section.
- Wolfspeed layout guidance is manufacturer guidance for module drivers; no AIPE parasitic extraction has quantified it.
- Creepage figures in PRD-09301 Figure 20 were not extracted.

## Source references

- PRD-09301 §1.4, §2.1–2.7, §3.8, §4, §6 (CGD1700HB2M-UNA analysis decisions 6–7).
- CGD15SG00D2 PCB layout section and fab drawing (analysis decision 7).
- TIDA-010054 layer plots (analysis decision 10).

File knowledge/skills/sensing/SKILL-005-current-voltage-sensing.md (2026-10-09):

# SKILL-005 — Current and voltage sensing

Status: **reference-derived** (cited calculations analytically checked) · Domain: sensing ·
Index: [`SKILL-005-current-voltage-sensing.json`](SKILL-005-current-voltage-sensing.json)

## Purpose

Select and design isolated voltage and current measurement chains for
high-voltage SiC converters: sensing element, isolation device, signal format
(analog vs. delta-sigma bitstream), scaling, filtering, fast protection paths
and supplies for the isolated side.

## Applicable conditions

- DC-bus, output and battery voltages of hundreds of volts; DC and switch-node/tank currents of tens of amperes (TIDA-010054: 800 V/12.5 A primary, 500 V/20 A secondary, 45 A/70 A tank trip levels).
- Controllers with ADCs and/or sigma-delta filter peripherals (C2000 SDFM).

## Not applicable / out of scope

- Non-isolated low-side current sensing at low voltage (e.g. INA240 in the Buck V1 benchmark).
- Current transformers and Rogowski coils (not used in the references; PRD-09301 §6.3 mentions them only for gate-current metrology).

## Engineering principles

1. **Rate every barrier part for the node** (KR-SN-001). TIDA-010054 uses reinforced isolated amplifiers/modulators (7–8 kVpk class) and a reinforced Hall sensor.
2. **Scale for linear range with headroom** (KR-SN-002): 800 V → 1.57 V of a 2 V input (EC-015); 500 V → 0.76 V of ±1 V (EC-016); 12.5 A × 3 mΩ = 37.5 mV and 20 A × 1.5 mΩ = 30 mV of ±50 mV (EC-017, EC-018).
3. **Signal format by distance**: analog isolated amplifier to a nearby ADC; delta-sigma bitstream for long paths, decoded by the MCU (KR-SN-003, single-reference).
4. **Shunts need Kelvin connection and input filtering** (KR-SN-004; existing PE-PCB-004).
5. **Fast protection is a hardware path.** Hall sensor with ~100 ns OC flag tripping PWM for tank current; DESAT for switches; ADC loops are too slow (KR-SN-005).
6. **HV dividers are distributed ladders.** Eight 634 kΩ resistors share ~100 V each at 800 V (EC-021); check each element's limiting voltage and the creepage along the ladder.
7. **Isolated-side supply** may be derived from the same-reference gate-bias supply via an LDO (TIDA-010054 §3.4.3) within the bias power budget.

## Design procedure

1. List measured quantities, ranges, accuracy and bandwidth needs, and protection thresholds.
2. For each: choose element (divider, shunt, Hall) and isolation device (AMC1311/AMC1302 analog; AMC1336/AMC1306 bitstream; TMCS1133 Hall).
3. Compute scaling at maximum operating and trip values; check shunt/divider dissipation and voltage stress.
4. Choose signal format and route (analog differential to conversion stage near ADC, or bitstream + clock to SDFM with delay compensation).
5. Design input filters and the isolated supply; budget its current on the gate-bias supply if shared.
6. Define fast protection paths and their thresholds; connect to PWM trip.
7. Plan calibration (TIDA-010054 Lab 2 calibrates voltage sensing).

## Component selection considerations

- AMC1311 (2 V input, gain 1, B grade ±0.2 %), AMC1302-Q1 (±50 mV, gain 41), AMC1336 (±1 V, 1.5 GΩ input), AMC1306M05 (±50 mV, CMOS bitstream), TMCS1133 (1 MHz, OC detection, 80 Arms).
- Check current datasheet revisions: TI's design guide states 1100 VDC working voltage for TMCS1133 while the 2026 datasheet states 1343 VDC reinforced; the BOM orderable number differs from current datasheet listings.
- 0.1 % divider resistors in the HV ladders; 3 W metal-element shunts.

## PCB constraints

- Divider ladders along the creepage path with keep-out from LV nets (KR-ISO-002).
- Shunt sense routed as a tight Kelvin pair to the filter at the IC (KR-SN-004).
- Bitstream clock/data short with series termination; analog differential outputs routed as pairs.
- Isolated-side ground and supply confined to their island (KR-ISO-001).

## Verification methods

- Calculation: scaling and dissipation (EC-015…EC-018, EC-021).
- Measurement: calibration against a reference meter; trip-level tests at low voltage (TIDA-010054 Lab 2 procedure sets low trip limits and raises phase shift until trip).
- Review: insulation coordination of each barrier part.

## Known limitations

- All sensing knowledge comes from one reference design (TIDA-010054) plus Wolfspeed protection guidance.
- Accuracy budgets (tolerance, drift, CMRR) were not computed.

## Source references

- TIDA-010054 [analysis](../../references/ti/tida-010054/analysis.md) decisions 6–7; TIDUES0 §3.2–3.4; BOM.
- PRD-09301 §5.1 (protection speed), §3.4 (isolated NTC feedback).

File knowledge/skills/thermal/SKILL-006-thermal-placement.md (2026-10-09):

# SKILL-006 — Power electronics thermal placement

Status: **reference-derived** (cited calculations analytically checked) · Domain: thermal ·
Index: [`SKILL-006-thermal-placement.json`](SKILL-006-thermal-placement.json)

## Purpose

Place power semiconductors, heat sinks, gate drivers and temperature sensors so
that each device's loss stays inside its thermal-path limit at worst-case
ambient, insulation between shared-sink devices is maintained, and temperature
feedback is used correctly.

## Applicable conditions

- Through-hole or module SiC devices on heat sinks with natural or forced air (TIDA-010054: 4 sinks, 2 TO-247-4 each, two 12 V fans).
- Boards where gate drivers must sit next to devices that are mounted to heat sinks.

## Not applicable / out of scope

- Liquid cooling, baseplate-module cold plates, transient thermal impedance/power cycling (Wolfspeed lifetime papers were not acquired).
- Detailed CFD.

## Engineering principles

1. **Steady-state budget along the real path.** P_max = (T_J,max − T_A,max)/R_th,total, with R_th,total = R_th,JC + R_th,interface + the device's effective share of the sink resistance (KR-TH-001). TI's model gives 50 W (C3M0075120K) and 69 W (C3M0030090K) at 40 °C ambient with two devices per 0.5 °C/W sink and 0.1 °C/W pads (EC-019, EC-020). TI does not explain the factor 2 on the sink term — AIPE reads it as two devices sharing one sink.
2. **Insulate shared sinks.** Exposed-drain packages on a common sink need a rated insulating interface, whose resistance enters the budget (KR-TH-002; TI uses CD-02-05-247 pads).
3. **Loss estimates first.** Conduction (I_rms²·R_DS(on) at temperature) plus switching (turn-off only under ZVS; add turn-on where ZVS is lost) (TIDUES0 §2.3.5). Losses change with operating point.
4. **Thermal placement must not lengthen electrical loops.** In TIDA-010054 the drivers sit on the opposite board side directly beside each device's leads, keeping gate loops short while the devices stand on the sinks (observed).
5. **Temperature feedback ≠ junction temperature.** NTC/thermistor readings track substrate or board temperature; isolate their feedback and calibrate (KR-TH-003; CB-PR-002).

## Design procedure

1. Compute per-device losses over the operating envelope (worst case, including loss of ZVS).
2. Choose sink, interface and airflow; compute P_max per device with the shared-sink model; require margin over worst-case loss.
3. Place devices on sinks so heat sources are spread and airflow is not blocked; keep film capacitors and magnetics out of exhaust where possible (AIPE recommendation without source evidence — review).
4. Place gate drivers and decoupling directly at the device leads (opposite side if needed) — SKILL-002.
5. Place thermistors where they represent the quantity to supervise; route through the driver's isolated analog channel or an isolator.
6. Plan measurement: case/sink thermocouples during full-load tests.

## Component selection considerations

- Heat sinks: thermal resistance at the actual airflow (TI: Ohmite CR201-50VE, 0.5 °C/W datasheet value).
- Interface pads: voltage rating and thermal resistance (Wakefield-Vette CD-02-05-247, 0.1 °C/W per TI).
- Fans: airflow and supply budget on the auxiliary rail (TI fans raise 12 V current from 1.14 A to 1.43 A).
- Temperature sensors: TI TMP6131 thermistor on the high-side driver AIN; module NTC on CGD1700HB2M-UNA.

## PCB constraints

- Keep-outs around heat-sink footprints and mounting hardware; creepage from sink (if grounded) to HV pins.
- Driver placement as in SKILL-002 (KR-PCB-005).

## Verification methods

- Calculation: P_max (EC-019, EC-020) against loss estimates.
- Simulation: PLECS-style thermal simulation (TI provides a PLECS model, not acquired).
- Measurement: temperatures at full load and worst ambient.

## Known limitations

- Single reference for the thermal budget (TIDA-010054); TI's model assumes 40 °C ambient and equal sharing; TI warns the design is only intended for room ambient.
- No transient or lifetime analysis.

## Source references

- TIDA-010054 [analysis](../../references/ti/tida-010054/analysis.md) decisions 9–10; TIDUES0 §2.3.5–2.3.5.6.
- CGD1700HB2M-UNA [analysis](../../references/wolfspeed/cgd1700hb2m-una/analysis.md) decision 8; PRD-09301 §3.4.

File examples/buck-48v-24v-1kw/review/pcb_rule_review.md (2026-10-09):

# V1 power-electronics PCB rule review

Separate review of the final routed CAD. **Human review required.**
Geometry measurements below are automated; their electrical acceptability is not.

| Rule / review question | Evidence and finding | Method / disposition |
|---|---|---|
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

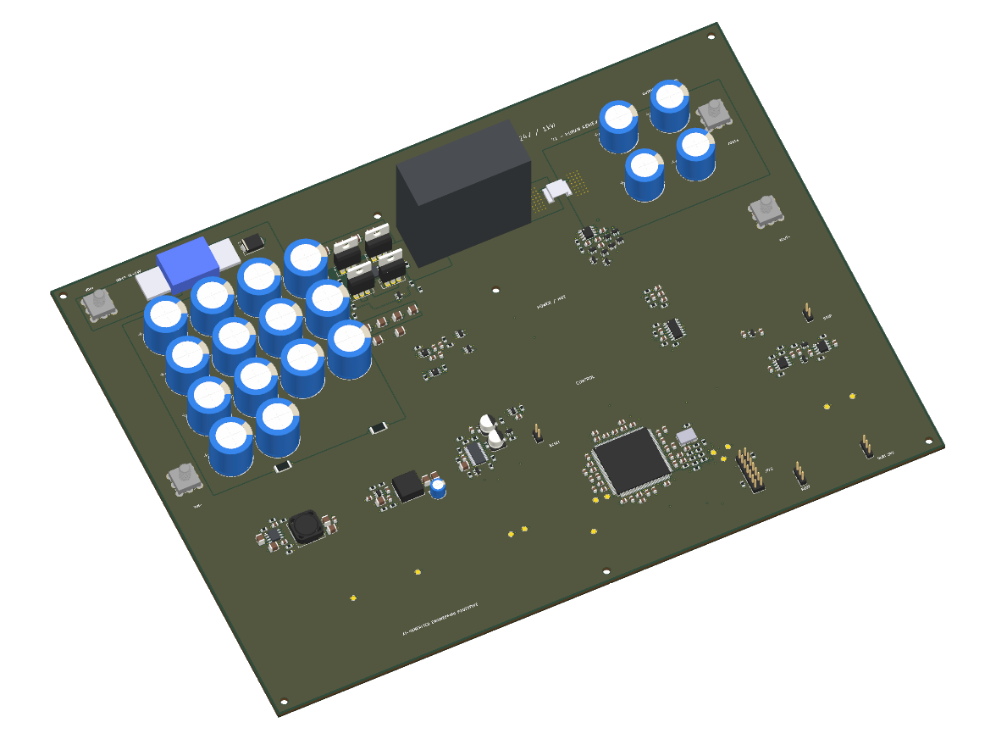
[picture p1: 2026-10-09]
examples/buck-48v-24v-1kw/releases/v1/review/pcb_3d.png

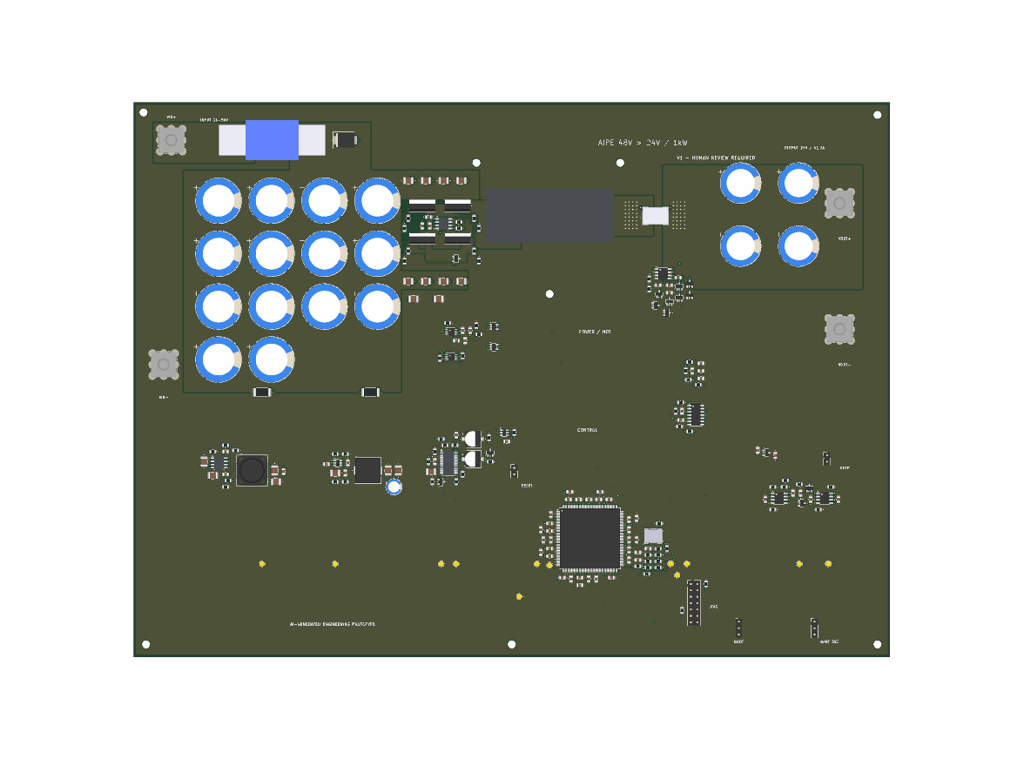
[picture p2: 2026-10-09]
examples/buck-48v-24v-1kw/review/pcb_front.png

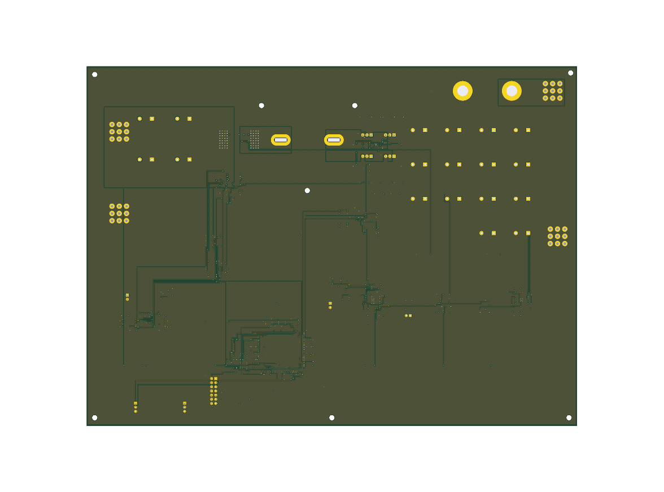
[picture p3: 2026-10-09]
examples/buck-48v-24v-1kw/releases/v1/review/pcb_back.png

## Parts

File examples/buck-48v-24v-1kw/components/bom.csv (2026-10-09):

Reference | Value | Manufacturer | MPN | Footprint | Datasheet | Assembly note
J1 | VIN+ | Wurth Elektronik | 74651195 | TerminalBlock_Wuerth:Wuerth_REDCUBE-THR_WP-THRSH_74651195_THR | https://www.we-online.com/components/products/datasheet/74651195.pdf | M5; 85 A at 20 C conditional on PCB and cable; support during torque
J2 | VIN- | Wurth Elektronik | 74651195 | TerminalBlock_Wuerth:Wuerth_REDCUBE-THR_WP-THRSH_74651195_THR | https://www.we-online.com/components/products/datasheet/74651195.pdf | M5; 85 A at 20 C conditional on PCB and cable; support during torque
J3 | VOUT+ | Wurth Elektronik | 74651195 | TerminalBlock_Wuerth:Wuerth_REDCUBE-THR_WP-THRSH_74651195_THR | https://www.we-online.com/components/products/datasheet/74651195.pdf | M5; 85 A at 20 C conditional on PCB and cable; support during torque
J4 | VOUT- | Wurth Elektronik | 74651195 | TerminalBlock_Wuerth:Wuerth_REDCUBE-THR_WP-THRSH_74651195_THR | https://www.we-online.com/components/products/datasheet/74651195.pdf | M5; 85 A at 20 C conditional on PCB and cable; support during torque
F1 | 40A/70V | Littelfuse | 4998040.M-NH | AIPE:MIDI_70V_M6_P30 | https://www.littelfuse.com/assetdocs/littelfuse-datasheet-4998-midihp70v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 | Bolt-down; hardware and insulating support required
D1 | SMCJ54A | Diodes Incorporated | SMCJ54A-13-F | Diode_SMD:D_SMC | https://www.diodes.com/part/view/SMCJ54A | 54 V standoff; 87.1 V max specified pulse clamp, not hotplug qualification
C1 | 470u/100V | Nippon Chemi-Con | EKY-101ELL471MM25S | Capacitor_THT:CP_Radial_D18.0mm_P7.50mm | https://www.chemi-con.co.jp/en/products/detail-condenser.php?part_number=EKY-101ELL471MM25S | 1.75 Arms at 105 C / 100 kHz; 36 mohm impedance max at 20 C
C2 | 470u/100V | Nippon Chemi-Con | EKY-101ELL471MM25S | Capacitor_THT:CP_Radial_D18.0mm_P7.50mm | https://www.chemi-con.co.jp/en/products/detail-condenser.php?part_number=EKY-101ELL471MM25S | 1.75 Arms at 105 C / 100 kHz; 36 mohm impedance max at 20 C
C3 | 470u/100V | Nippon Chemi-Con | EKY-101ELL471MM25S | Capacitor_THT:CP_Radial_D18.0mm_P7.50mm | https://www.chemi-con.co.jp/en/products/detail-condenser.php?part_number=EKY-101ELL471MM25S | 1.75 Arms at 105 C / 100 kHz; 36 mohm impedance max at 20 C
C4 | 470u/100V | Nippon Chemi-Con | EKY-101ELL471MM25S | Capacitor_THT:CP_Radial_D18.0mm_P7.50mm | https://www.chemi-con.co.jp/en/products/detail-condenser.php?part_number=EKY-101ELL471MM25S | 1.75 Arms at 105 C / 100 kHz; 36 mohm impedance max at 20 C
C5 | 470u/100V | Nippon Chemi-Con | EKY-101ELL471MM25S | Capacitor_THT:CP_Radial_D18.0mm_P7.50mm | https://www.chemi-con.co.jp/en/products/detail-condenser.php?part_number=EKY-101ELL471MM25S | 1.75 Arms at 105 C / 100 kHz; 36 mohm impedance max at 20 C
C6 | 470u/100V | Nippon Chemi-Con | EKY-101ELL471MM25S | Capacitor_THT:CP_Radial_D18.0mm_P7.50mm | https://www.chemi-con.co.jp/en/products/detail-condenser.php?part_number=EKY-101ELL471MM25S | 1.75 Arms at 105 C / 100 kHz; 36 mohm impedance max at 20 C
C7 | 470u/100V | Nippon Chemi-Con | EKY-101ELL471MM25S | Capacitor_THT:CP_Radial_D18.0mm_P7.50mm | https://www.chemi-con.co.jp/en/products/detail-condenser.php?part_number=EKY-101ELL471MM25S | 1.75 Arms at 105 C / 100 kHz; 36 mohm impedance max at 20 C
C8 | 470u/100V | Nippon Chemi-Con | EKY-101ELL471MM25S | Capacitor_THT:CP_Radial_D18.0mm_P7.50mm | https://www.chemi-con.co.jp/en/products/detail-condenser.php?part_number=EKY-101ELL471MM25S | 1.75 Arms at 105 C / 100 kHz; 36 mohm impedance max at 20 C
C9 | 470u/100V | Nippon Chemi-Con | EKY-101ELL471MM25S | Capacitor_THT:CP_Radial_D18.0mm_P7.50mm | https://www.chemi-con.co.jp/en/products/detail-condenser.php?part_number=EKY-101ELL471MM25S | 1.75 Arms at 105 C / 100 kHz; 36 mohm impedance max at 20 C
C10 | 470u/100V | Nippon Chemi-Con | EKY-101ELL471MM25S | Capacitor_THT:CP_Radial_D18.0mm_P7.50mm | https://www.chemi-con.co.jp/en/products/detail-condenser.php?part_number=EKY-101ELL471MM25S | 1.75 Arms at 105 C / 100 kHz; 36 mohm impedance max at 20 C
C11 | 470u/100V | Nippon Chemi-Con | EKY-101ELL471MM25S | Capacitor_THT:CP_Radial_D18.0mm_P7.50mm | https://www.chemi-con.co.jp/en/products/detail-condenser.php?part_number=EKY-101ELL471MM25S | 1.75 Arms at 105 C / 100 kHz; 36 mohm impedance max at 20 C
C12 | 470u/100V | Nippon Chemi-Con | EKY-101ELL471MM25S | Capacitor_THT:CP_Radial_D18.0mm_P7.50mm | https://www.chemi-con.co.jp/en/products/detail-condenser.php?part_number=EKY-101ELL471MM25S | 1.75 Arms at 105 C / 100 kHz; 36 mohm impedance max at 20 C
C13 | 470u/100V | Nippon Chemi-Con | EKY-101ELL471MM25S | Capacitor_THT:CP_Radial_D18.0mm_P7.50mm | https://www.chemi-con.co.jp/en/products/detail-condenser.php?part_number=EKY-101ELL471MM25S | 1.75 Arms at 105 C / 100 kHz; 36 mohm impedance max at 20 C
C14 | 470u/100V | Nippon Chemi-Con | EKY-101ELL471MM25S | Capacitor_THT:CP_Radial_D18.0mm_P7.50mm | https://www.chemi-con.co.jp/en/products/detail-condenser.php?part_number=EKY-101ELL471MM25S | 1.75 Arms at 105 C / 100 kHz; 36 mohm impedance max at 20 C
C15 | 2.2u/100V | TDK | CGA6N3X7R2A225K230AB | Capacitor_SMD:C_1210_3225Metric | https://product.tdk.com/en/search/capacitor/ceramic/mlcc/info?part_no=CGA6N3X7R2A225K230AB | Local commutation bypass; do not credit nominal capacitance under bias
C16 | 2.2u/100V | TDK | CGA6N3X7R2A225K230AB | Capacitor_SMD:C_1210_3225Metric | https://product.tdk.com/en/search/capacitor/ceramic/mlcc/info?part_no=CGA6N3X7R2A225K230AB | Local commutation bypass; do not credit nominal capacitance under bias
C17 | 2.2u/100V | TDK | CGA6N3X7R2A225K230AB | Capacitor_SMD:C_1210_3225Metric | https://product.tdk.com/en/search/capacitor/ceramic/mlcc/info?part_no=CGA6N3X7R2A225K230AB | Local commutation bypass; do not credit nominal capacitance under bias
C18 | 2.2u/100V | TDK | CGA6N3X7R2A225K230AB | Capacitor_SMD:C_1210_3225Metric | https://product.tdk.com/en/search/capacitor/ceramic/mlcc/info?part_no=CGA6N3X7R2A225K230AB | Local commutation bypass; do not credit nominal capacitance under bias
C19 | 2.2u/100V | TDK | CGA6N3X7R2A225K230AB | Capacitor_SMD:C_1210_3225Metric | https://product.tdk.com/en/search/capacitor/ceramic/mlcc/info?part_no=CGA6N3X7R2A225K230AB | Local commutation bypass; do not credit nominal capacitance under bias
C20 | 2.2u/100V | TDK | CGA6N3X7R2A225K230AB | Capacitor_SMD:C_1210_3225Metric | https://product.tdk.com/en/search/capacitor/ceramic/mlcc/info?part_no=CGA6N3X7R2A225K230AB | Local commutation bypass; do not credit nominal capacitance under bias
C21 | 2.2u/100V | TDK | CGA6N3X7R2A225K230AB | Capacitor_SMD:C_1210_3225Metric | https://product.tdk.com/en/search/capacitor/ceramic/mlcc/info?part_no=CGA6N3X7R2A225K230AB | Local commutation bypass; do not credit nominal capacitance under bias
C22 | 2.2u/100V | TDK | CGA6N3X7R2A225K230AB | Capacitor_SMD:C_1210_3225Metric | https://product.tdk.com/en/search/capacitor/ceramic/mlcc/info?part_no=CGA6N3X7R2A225K230AB | Local commutation bypass; do not credit nominal capacitance under bias
Q1 | CSD19536KCS | Texas Instruments | CSD19536KCS | Package_TO_SOT_THT:TO-220-3_Vertical | https://www.ti.com/lit/ds/symlink/csd19536kcs.pdf | Tab=drain. Individual insulated thermal interface required.
R1 | 4.7 | Yageo | RC0805FR-074R7L | Resistor_SMD:R_0805_2012Metric | https://www.yageo.com/en/Chart/Download/pdf/RC0805
R2 | 10k | Yageo | RC0805FR-0710KL | Resistor_SMD:R_0805_2012Metric | https://www.yageo.com/en/Chart/Download/pdf/RC0805
Q2 | CSD19536KCS | Texas Instruments | CSD19536KCS | Package_TO_SOT_THT:TO-220-3_Vertical | https://www.ti.com/lit/ds/symlink/csd19536kcs.pdf | Tab=drain. Individual insulated thermal interface required.
R3 | 4.7 | Yageo | RC0805FR-074R7L | Resistor_SMD:R_0805_2012Metric | https://www.yageo.com/en/Chart/Download/pdf/RC0805
R4 | 10k | Yageo | RC0805FR-0710KL | Resistor_SMD:R_0805_2012Metric | https://www.yageo.com/en/Chart/Download/pdf/RC0805
Q3 | CSD19536KCS | Texas Instruments | CSD19536KCS | Package_TO_SOT_THT:TO-220-3_Vertical | https://www.ti.com/lit/ds/symlink/csd19536kcs.pdf | Tab=drain. Individual insulated thermal interface required.
R5 | 4.7 | Yageo | RC0805FR-074R7L | Resistor_SMD:R_0805_2012Metric | https://www.yageo.com/en/Chart/Download/pdf/RC0805
R6 | 10k | Yageo | RC0805FR-0710KL | Resistor_SMD:R_0805_2012Metric | https://www.yageo.com/en/Chart/Download/pdf/RC0805
Q4 | CSD19536KCS | Texas Instruments | CSD19536KCS | Package_TO_SOT_THT:TO-220-3_Vertical | https://www.ti.com/lit/ds/symlink/csd19536kcs.pdf | Tab=drain. Individual insulated thermal interface required.
R7 | 4.7 | Yageo | RC0805FR-074R7L | Resistor_SMD:R_0805_2012Metric | https://www.yageo.com/en/Chart/Download/pdf/RC0805
R8 | 10k | Yageo | RC0805FR-0710KL | Resistor_SMD:R_0805_2012Metric | https://www.yageo.com/en/Chart/Download/pdf/RC0805
L1 | 10uH/83A | Vishay | IHXL2000VZEB100M3A | AIPE:IHXL2000VZ_10uH_Upright | https://www.vishay.com/docs/34681/ihxl2000vz-3a.pdf | 83 A thermal / 83 A at 20% L drop; 0.86 mohm max; custom support required
R9 | 2m/6W/Kelvin | Bourns | CSS4J-4026K-2L00F | AIPE:CSS4J_4026_Kelvin | https://www.bourns.com/docs/product-datasheets/css4j-4026.pdf | 6 W at 70 C terminal; 1%; 4-terminal
C23 | 1000u/50V | Nippon Chemi-Con | EKY-500ELL102ML25S | Capacitor_THT:CP_Radial_D16.0mm_P7.50mm | https://www.chemi-con.co.jp/en/products/detail-condenser.php?part_number=EKY-500ELL102ML25S | 2.555 Arms / 25 mohm impedance at 100 kHz
C24 | 1000u/50V | Nippon Chemi-Con | EKY-500ELL102ML25S | Capacitor_THT:CP_Radial_D16.0mm_P7.50mm | https://www.chemi-con.co.jp/en/products/detail-condenser.php?part_number=EKY-500ELL102ML25S | 2.555 Arms / 25 mohm impedance at 100 kHz
C25 | 1000u/50V | Nippon Chemi-Con | EKY-500ELL102ML25S | Capacitor_THT:CP_Radial_D16.0mm_P7.50mm | https://www.chemi-con.co.jp/en/products/detail-condenser.php?part_number=EKY-500ELL102ML25S | 2.555 Arms / 25 mohm impedance at 100 kHz
C26 | 1000u/50V | Nippon Chemi-Con | EKY-500ELL102ML25S | Capacitor_THT:CP_Radial_D16.0mm_P7.50mm | https://www.chemi-con.co.jp/en/products/detail-condenser.php?part_number=EKY-500ELL102ML25S | 2.555 Arms / 25 mohm impedance at 100 kHz
C27 | 22u/25V | Taiyo Yuden | TMK325B7226KMHT | Capacitor_SMD:C_1210_3225Metric | https://ds.yuden.co.jp/TYCOMPAS/eu/detail?pn=TMK325B7226KMHT&u=M | ; manufacturer status Non-preferred; sourcing review required
C28 | 22u/25V | Taiyo Yuden | TMK325B7226KMHT | Capacitor_SMD:C_1210_3225Metric | https://ds.yuden.co.jp/TYCOMPAS/eu/detail?pn=TMK325B7226KMHT&u=M | ; manufacturer status Non-preferred; sourcing review required
R10 | 10k | Yageo | RC2512FR-0710KL | Resistor_SMD:R_2512_6332Metric | https://www.yageo.com/en/Chart/Download/pdf/RC0805 | Input bleeder ~0.23 W nominal
R11 | 2.4k | Yageo | RC2512FR-072K4L | Resistor_SMD:R_2512_6332Metric | https://www.yageo.com/en/Chart/Download/pdf/RC0805 | Output bleeder 0.24 W nominal
U1 | UCC27211DDAR | Texas Instruments | UCC27211DDAR | Package_SO:SOIC-8-1EP_3.9x4.9mm_P1.27mm_EP2.95x4.9mm_Mask2.71x3.4mm | https://www.ti.com/lit/ds/symlink/ucc27211.pdf
C29 | 2.2u/25V | Murata | GRM21BR71E225KA73L | Capacitor_SMD:C_0805_2012Metric | https://www.murata.com/-/media/webrenewal/tool/library/common-pdf/dynamic-model/component-list-d-mlcc-2506.ashx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
C30 | 100n/50V | Murata | GRM21BR71H104KA01L | Capacitor_SMD:C_0805_2012Metric | https://pim.murata.com/asset/pim4/ceramicCapacitorSMD/GRM21BR71H104KA01-01-EN_PDF_CERAMICCAPACITORSMD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
C31 | 100n/50V | Murata | GRM21BR71H104KA01L | Capacitor_SMD:C_0805_2012Metric | https://pim.murata.com/asset/pim4/ceramicCapacitorSMD/GRM21BR71H104KA01-01-EN_PDF_CERAMICCAPACITORSMD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
R12 | 10k | Yageo | RC0805FR-0710KL | Resistor_SMD:R_0805_2012Metric | https://www.yageo.com/en/Chart/Download/pdf/RC0805
R13 | 10k | Yageo | RC0805FR-0710KL | Resistor_SMD:R_0805_2012Metric | https://www.yageo.com/en/Chart/Download/pdf/RC0805
U2 | LM5164DDAR | Texas Instruments | LM5164DDAR | Package_SO:SOIC-8-1EP_3.9x4.9mm_P1.27mm_EP2.95x4.9mm_Mask2.71x3.4mm | https://www.ti.com/lit/ds/symlink/lm5164.pdf
C32 | 2.2u/100V | TDK | CGA6N3X7R2A225K230AB | Capacitor_SMD:C_1210_3225Metric | https://product.tdk.com/en/search/capacitor/ceramic/mlcc/info?part_no=CGA6N3X7R2A225K230AB
C33 | 2.2u/100V | TDK | CGA6N3X7R2A225K230AB | Capacitor_SMD:C_1210_3225Metric | https://product.tdk.com/en/search/capacitor/ceramic/mlcc/info?part_no=CGA6N3X7R2A225K230AB
C34 | 2.2n/50V | KEMET | C0805C222K5RACTU | Capacitor_SMD:C_0805_2012Metric | https://content.kemet.com/datasheets/KEM_C1002_X7R_SMD.pdf
L2 | 68uH | Coilcraft | MSS1246T-683MLC | Inductor_SMD:L_Coilcraft_MSS1246T-XXX | https://www.ti.com/lit/ds/symlink/lm5164.pdf
C35 | 22u/25V | Taiyo Yuden | TMK325B7226KMHT | Capacitor_SMD:C_1210_3225Metric | https://ds.yuden.co.jp/TYCOMPAS/eu/detail?pn=TMK325B7226KMHT&u=M | ; manufacturer status Non-preferred; sourcing review required
C36 | 22u/25V | Taiyo Yuden | TMK325B7226KMHT | Capacitor_SMD:C_1210_3225Metric | https://ds.yuden.co.jp/TYCOMPAS/eu/detail?pn=TMK325B7226KMHT&u=M | ; manufacturer status Non-preferred; sourcing review required
R14 | 100k | Yageo | RC0805FR-07100KL | Resistor_SMD:R_0805_2012Metric | https://www.yageo.com/en/Chart/Download/pdf/RC0805
R15 | 453k | Yageo | RC0805FR-07453KL | Resistor_SMD:R_0805_2012Metric | https://www.yageo.com/en/Chart/Download/pdf/RC0805
R16 | 49.9k | Yageo | RC0805FR-0749K9L | Resistor_SMD:R_0805_2012Metric | https://www.yageo.com/en/Chart/Download/pdf/RC0805
R17 | 453k | Yageo | RC0805FR-07453KL | Resistor_SMD:R_0805_2012Metric | https://www.yageo.com/en/Chart/Download/pdf/RC0805
R18 | 10k | Yageo | RC0805FR-0710KL | Resistor_SMD:R_0805_2012Metric | https://www.yageo.com/en/Chart/Download/pdf/RC0805
C37 | 3.3n/50V | KEMET | C0805C332K5RACTU | Capacitor_SMD:C_0805_2012Metric | https://content.kemet.com/datasheets/KEM_C1002_X7R_SMD.pdf
C38 | 56p/50V | KEMET | C0805C560J5GACTU | Capacitor_SMD:C_0805_2012Metric | https://content.kemet.com/datasheets/KEM_C1003_C0G_SMD.pdf
U3 | TPS54302DDCR | Texas Instruments | TPS54302DDCR | Package_TO_SOT_SMD:SOT-23-6 | https://www.ti.com/lit/ds/symlink/tps54302.pdf
R19 | 100k | Yageo | RC0805FR-07100KL | Resistor_SMD:R_0805_2012Metric | https://www.yageo.com/en/Chart/Download/pdf/RC0805
R20 | 20k | Yageo | RC0805FR-0720KL | Resistor_SMD:R_0805_2012Metric | https://www.yageo.com/en/Chart/Download/pdf/RC0805
C39 | 100n/50V | Murata | GRM21BR71H104KA01L | Capacitor_SMD:C_0805_2012Metric | https://pim.murata.com/asset/pim4/ceramicCapacitorSMD/GRM21BR71H104KA01-01-EN_PDF_CERAMICCAPACITORSMD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
C40 | 22u/25V | Taiyo Yuden | TMK325B7226KMHT | Capacitor_SMD:C_1210_3225Metric | https://ds.yuden.co.jp/TYCOMPAS/eu/detail?pn=TMK325B7226KMHT&u=M | ; manufacturer status Non-preferred; sourcing review required
C41 | 100n/50V | Murata | GRM21BR71H104KA01L | Capacitor_SMD:C_0805_2012Metric | https://pim.murata.com/asset/pim4/ceramicCapacitorSMD/GRM21BR71H104KA01-01-EN_PDF_CERAMICCAPACITORSMD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
L3 | 10uH | Coilcraft | MSS1048-103MLC | Inductor_SMD:L_Coilcraft_MSS1048-XXX | https://www.coilcraft.com/en-us/products/power/shielded-inductors/ferrite-drum/mss-mos/mss1048/mss1048-103/
C42 | 22u/25V | Taiyo Yuden | TMK325B7226KMHT | Capacitor_SMD:C_1210_3225Metric | https://ds.yuden.co.jp/TYCOMPAS/eu/detail?pn=TMK325B7226KMHT&u=M | ; manufacturer status Non-preferred; sourcing review required
C43 | 22u/25V | Taiyo Yuden | TMK325B7226KMHT | Capacitor_SMD:C_1210_3225Metric | https://ds.yuden.co.jp/TYCOMPAS/eu/detail?pn=TMK325B7226KMHT&u=M | ; manufacturer status Non-preferred; sourcing review required
R21 | 100k | Yageo | RC0805FR-07100KL | Resistor_SMD:R_0805_2012Metric | https://www.yageo.com/en/Chart/Download/pdf/RC0805
R22 | 13.3k | Yageo | RC0805FR-0713K3L | Resistor_SMD:R_0805_2012Metric | https://www.yageo.com/en/Chart/Download/pdf/RC0805
C44 | 56p/50V | KEMET | C0805C560J5GACTU | Capacitor_SMD:C_0805_2012Metric | https://content.kemet.com/datasheets/KEM_C1003_C0G_SMD.pdf
C45 | 220u/16V | Panasonic | EEU-FR1C221 | Capacitor_THT:CP_Radial_D6.3mm_P2.50mm | https://industrial.panasonic.com/ww/products/pt/aluminum-cap-lead/models/EEUFR1C221 | Bulk hold-up; power-down timing needs measurement
U4 | TPS767D301PWPR | Texas Instruments | TPS767D301PWPR | Package_SO:HTSSOP-28-1EP_4.4x9.7mm_P0.65mm_EP2.85x5.4mm | https://www.ti.com/lit/ds/symlink/tps767d3.pdf
R23 | 18.2k | Yageo | RC0805FR-0718K2L | Resistor_SMD:R_0805_2012Metric | https://www.yageo.com/en/Chart/Download/pdf/RC0805
R24 | 30.1k | Yageo | RC0805FR-0730K1L | Resistor_SMD:R_0805_2012Metric | https://www.yageo.com/en/Chart/Download/pdf/RC0805
R25 | 10k | Yageo | RC0805FR-0710KL | Resistor_SMD:R_0805_2012Metric | https://www.yageo.com/en/Chart/Download/pdf/RC0805
R26 | 10k | Yageo | RC0805FR-0710KL | Resistor_SMD:R_0805_2012Metric | https://www.yageo.com/en/Chart/Download/pdf/RC0805
R27 | 10k | Yageo | RC0805FR-0710KL | Resistor_SMD:R_0805_2012Metric | https://www.yageo.com/en/Chart/Download/pdf/RC0805
R28 | 100k | Yageo | RC0805FR-07100KL | Resistor_SMD:R_0805_2012Metric | https://www.yageo.com/en/Chart/Download/pdf/RC0805
Q5 | MMBT3904 | Nexperia | MMBT3904,215 | Package_TO_SOT_SMD:SOT-23 | https://assets.nexperia.com/documents/data-sheet/MMBT3904.pdf
D2 | BAT54 | Nexperia | BAT54,215 | Package_TO_SOT_SMD:SOT-23 | https://assets.nexperia.com/documents/data-sheet/BAT54_SER.pdf | Core failure asserts reset without 5 V pull-up on DSP
R29 | 0.1 | Yageo | RC0805FR-070R1L | Resistor_SMD:R_0805_2012Metric | https://www.yageo.com/en/Chart/Download/pdf/RC0805 | Explicit output-capacitor ESR for LDO stability
C46 | 100u/6.3V | Panasonic | 6SVP100M | Capacitor_SMD:CP_Elec_6.3x5.8 | https://industrial.panasonic.com/ww/products/pt/os-con/models/6SVP100M | Low ESR polymer in series with 0.1 ohm; verify LDO stability
R30 | 0.1 | Yageo | RC0805FR-070R1L | Resistor_SMD:R_0805_2012Metric | https://www.yageo.com/en/Chart/Download/pdf/RC0805 | Explicit output-capacitor ESR for LDO stability
C47 | 100u/6.3V | Panasonic | 6SVP100M | Capacitor_SMD:CP_Elec_6.3x5.8 | https://industrial.panasonic.com/ww/products/pt/os-con/models/6SVP100M | Low ESR polymer in series with 0.1 ohm; verify LDO stability
C48 | 100n/50V | Murata | GRM21BR71H104KA01L | Capacitor_SMD:C_0805_2012Metric | https://pim.murata.com/asset/pim4/ceramicCapacitorSMD/GRM21BR71H104KA01-01-EN_PDF_CERAMICCAPACITORSMD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
C49 | 22u/25V | Taiyo Yuden | TMK325B7226KMHT | Capacitor_SMD:C_1210_3225Metric | https://ds.yuden.co.jp/TYCOMPAS/eu/detail?pn=TMK325B7226KMHT&u=M | ; manufacturer status Non-preferred; sourcing review required
U5 | TPS3808G01DBVR | Texas Instruments | TPS3808G01DBVR | Package_TO_SOT_SMD:SOT-23-6 | https://www.ti.com/lit/ds/symlink/tps3808.pdf
R31 | 105k | Yageo | RC0805FR-07105KL | Resistor_SMD:R_0805_2012Metric | https://www.yageo.com/en/Chart/Download/pdf/RC0805
R32 | 10k | Yageo | RC0805FR-0710KL | Resistor_SMD:R_0805_2012Metric | https://www.yageo.com/en/Chart/Download/pdf/RC0805
C50 | 10n/50V | KEMET | C0805C103K5RACTU | Capacitor_SMD:C_0805_2012Metric | https://content.kemet.com/datasheets/KEM_C1002_X7R_SMD.pdf
C51 | 100n/50V | Murata | GRM21BR71H104KA01L | Capacitor_SMD:C_0805_2012Metric | https://pim.murata.com/asset/pim4/ceramicCapacitorSMD/GRM21BR71H104KA01-01-EN_PDF_CERAMICCAPACITORSMD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
R33 | 10k | Yageo | RC0805FR-0710KL | Resistor_SMD:R_0805_2012Metric | https://www.yageo.com/en/Chart/Download/pdf/RC0805
J5 | RESET | Samtec | TSW-002-07-G-S | Connector_PinHeader_2.54mm:PinHeader_1x02_P2.54mm_Vertical | https://www.samtec.com/products/tsw | RESET
U6 | INA240A1DR | Texas Instruments | INA240A1DR | Package_SO:SOIC-8_3.9x4.9mm_P1.27mm | https://www.ti.com/lit/ds/symlink/ina240.pdf
R34 | 10 | Yageo | RC0805FR-0710RL | Resistor_SMD:R_0805_2012Metric | https://www.yageo.com/en/Chart/Download/pdf/RC0805
R35 | 10 | Yageo | RC0805FR-0710RL | Resistor_SMD:R_0805_2012Metric | https://www.yageo.com/en/Chart/Download/pdf/RC0805
C52 | 1n/50V | KEMET | C0805C102J5GACTU | Capacitor_SMD:C_0805_2012Metric | https://content.kemet.com/datasheets/KEM_C1003_C0G_SMD.pdf
C53 | 100n/50V | Murata | GRM21BR71H104KA01L | Capacitor_SMD:C_0805_2012Metric | https://pim.murata.com/asset/pim4/ceramicCapacitorSMD/GRM21BR71H104KA01-01-EN_PDF_CERAMICCAPACITORSMD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
R36 | 121k | Yageo | RC0805FR-07121KL | Resistor_SMD:R_0805_2012Metric | https://www.yageo.com/en/Chart/Download/pdf/RC0805
R37 | 4.99k | Yageo | RC0805FR-074K99L | Resistor_SMD:R_0805_2012Metric | https://www.yageo.com/en/Chart/Download/pdf/RC0805
C54 | 1n/50V | KEMET | C0805C102J5GACTU | Capacitor_SMD:C_0805_2012Metric | https://content.kemet.com/datasheets/KEM_C1003_C0G_SMD.pdf
R38 | 49.9k | Yageo | RC0805FR-0749K9L | Resistor_SMD:R_0805_2012Metric | https://www.yageo.com/en/Chart/Download/pdf/RC0805
R39 | 4.99k | Yageo | RC0805FR-074K99L | Resistor_SMD:R_0805_2012Metric | https://www.yageo.com/en/Chart/Download/pdf/RC0805
C55 | 1n/50V | KEMET | C0805C102J5GACTU | Capacitor_SMD:C_0805_2012Metric | https://content.kemet.com/datasheets/KEM_C1003_C0G_SMD.pdf
U7 | LM61CIM3/NOPB | Texas Instruments | LM61CIM3/NOPB | Package_TO_SOT_SMD:SOT-23 | https://www.ti.com/lit/ds/symlink/lm61.pdf | Place adjacent to the low-side MOSFET area
C56 | 100n/50V | Murata | GRM21BR71H104KA01L | Capacitor_SMD:C_0805_2012Metric | https://pim.murata.com/asset/pim4/ceramicCapacitorSMD/GRM21BR71H104KA01-01-EN_PDF_CERAMICCAPACITORSMD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
U8 | TLV9004IDR | Texas Instruments | TLV9004IDR | Package_SO:SOIC-14_3.9x8.7mm_P1.27mm | https://www.ti.com/lit/ds/symlink/tlv9004.pdf
C57 | 100n/50V | Murata | GRM21BR71H104KA01L | Capacitor_SMD:C_0805_2012Metric | https://pim.murata.com/asset/pim4/ceramicCapacitorSMD/GRM21BR71H104KA01-01-EN_PDF_CERAMICCAPACITORSMD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
R40 | 100 | Yageo | RC0805FR-07100RL | Resistor_SMD:R_0805_2012Metric | https://www.yageo.com/en/Chart/Download/pdf/RC0805
C58 | 1n/50V | KEMET | C0805C102J5GACTU | Capacitor_SMD:C_0805_2012Metric | https://content.kemet.com/datasheets/KEM_C1003_C0G_SMD.pdf
D3 | BAT54 | Nexperia | BAT54,215 | Package_TO_SOT_SMD:SOT-23 | https://assets.nexperia.com/documents/data-sheet/BAT54_SER.pdf | ADC positive clamp; 3 V full-scale, rail clamp is not a precision limiter
D4 | BAT54 | Nexperia | BAT54,215 | Package_TO_SOT_SMD:SOT-23 | https://assets.nexperia.com/documents/data-sheet/BAT54_SER.pdf | ADC negative clamp
R41 | 100 | Yageo | RC0805FR-07100RL | Resistor_SMD:R_0805_2012Metric | https://www.yageo.com/en/Chart/Download/pdf/RC0805
C59 | 1n/50V | KEMET | C0805C102J5GACTU | Capacitor_SMD:C_0805_2012Metric | https://content.kemet.com/datasheets/KEM_C1003_C0G_SMD.pdf
D5 | BAT54 | Nexperia | BAT54,215 | Package_TO_SOT_SMD:SOT-23 | https://assets.nexperia.com/documents/data-sheet/BAT54_SER.pdf | ADC positive clamp; 3 V full-scale, rail clamp is not a precision limiter
D6 | BAT54 | Nexperia | BAT54,215 | Package_TO_SOT_SMD:SOT-23 | https://assets.nexperia.com/documents/data-sheet/BAT54_SER.pdf | ADC negative clamp
R42 | 100 | Yageo | RC0805FR-07100RL | Resistor_SMD:R_0805_2012Metric | https://www.yageo.com/en/Chart/Download/pdf/RC0805
C60 | 1n/50V | KEMET | C0805C102J5GACTU | Capacitor_SMD:C_0805_2012Metric | https://content.kemet.com/datasheets/KEM_C1003_C0G_SMD.pdf
D7 | BAT54 | Nexperia | BAT54,215 | Package_TO_SOT_SMD:SOT-23 | https://assets.nexperia.com/documents/data-sheet/BAT54_SER.pdf | ADC positive clamp; 3 V full-scale, rail clamp is not a precision limiter
D8 | BAT54 | Nexperia | BAT54,215 | Package_TO_SOT_SMD:SOT-23 | https://assets.nexperia.com/documents/data-sheet/BAT54_SER.pdf | ADC negative clamp
R43 | 100 | Yageo | RC0805FR-07100RL | Resistor_SMD:R_0805_2012Metric | https://www.yageo.com/en/Chart/Download/pdf/RC0805
C61 | 1n/50V | KEMET | C0805C102J5GACTU | Capacitor_SMD:C_0805_2012Metric | https://content.kemet.com/datasheets/KEM_C1003_C0G_SMD.pdf
D9 | BAT54 | Nexperia | BAT54,215 | Package_TO_SOT_SMD:SOT-23 | https://assets.nexperia.com/documents/data-sheet/BAT54_SER.pdf | ADC positive clamp; 3 V full-scale, rail clamp is not a precision limiter
D10 | BAT54 | Nexperia | BAT54,215 | Package_TO_SOT_SMD:SOT-23 | https://assets.nexperia.com/documents/data-sheet/BAT54_SER.pdf | ADC negative clamp
U9 | REF3125AIDBZR | Texas Instruments | REF3125AIDBZR | Package_TO_SOT_SMD:SOT-23 | https://www.ti.com/lit/gpn/REF31
C62 | 100n/50V | Murata | GRM21BR71H104KA01L | Capacitor_SMD:C_0805_2012Metric | https://pim.murata.com/asset/pim4/ceramicCapacitorSMD/GRM21BR71H104KA01-01-EN_PDF_CERAMICCAPACITORSMD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
C63 | 2.2u/25V | Murata | GRM21BR71E225KA73L | Capacitor_SMD:C_0805_2012Metric | https://www.murata.com/-/media/webrenewal/tool/library/common-pdf/dynamic-model/component-list-d-mlcc-2506.ashx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
R44 | 1k | Yageo | RC0805FR-071KL | Resistor_SMD:R_0805_2012Metric | https://www.yageo.com/en/Chart/Download/pdf/RC0805
R45 | 24k | Yageo | RC0805FR-0724KL | Resistor_SMD:R_0805_2012Metric | https://www.yageo.com/en/Chart/Download/pdf/RC0805
C64 | 100n/50V | Murata | GRM21BR71H104KA01L | Capacitor_SMD:C_0805_2012Metric | https://pim.murata.com/asset/pim4/ceramicCapacitorSMD/GRM21BR71H104KA01-01-EN_PDF_CERAMICCAPACITORSMD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
R46 | 10k | Yageo | RC0805FR-0710KL | Resistor_SMD:R_0805_2012Metric | https://www.yageo.com/en/Chart/Download/pdf/RC0805
R47 | 15k | Yageo | RC0805FR-0715KL | Resistor_SMD:R_0805_2012Metric | https://www.yageo.com/en/Chart/Download/pdf/RC0805
C65 | 100n/50V | Murata | GRM21BR71H104KA01L | Capacitor_SMD:C_0805_2012Metric | https://pim.murata.com/asset/pim4/ceramicCapacitorSMD/GRM21BR71H104KA01-01-EN_PDF_CERAMICCAPACITORSMD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
R48 | 51k | Yageo | RC0805FR-0751KL | Resistor_SMD:R_0805_2012Metric | https://www.yageo.com/en/Chart/Download/pdf/RC0805
R49 | 62k | Yageo | RC0805FR-0762KL | Resistor_SMD:R_0805_2012Metric | https://www.yageo.com/en/Chart/Download/pdf/RC0805
C66 | 100n/50V | Murata | GRM21BR71H104KA01L | Capacitor_SMD:C_0805_2012Metric | https://pim.murata.com/asset/pim4/ceramicCapacitorSMD/GRM21BR71H104KA01-01-EN_PDF_CERAMICCAPACITORSMD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
U10 | LM2903BDR | Texas Instruments | LM2903BDR | Package_SO:SOIC-8_3.9x4.9mm_P1.27mm | https://www.ti.com/lit/ds/symlink/lm2903b.pdf
U11 | LM2903BDR | Texas Instruments | LM2903BDR | Package_SO:SOIC-8_3.9x4.9mm_P1.27mm | https://www.ti.com/lit/ds/symlink/lm2903b.pdf
C67 | 100n/50V | Murata | GRM21BR71H104KA01L | Capacitor_SMD:C_0805_2012Metric | https://pim.murata.com/asset/pim4/ceramicCapacitorSMD/GRM21BR71H104KA01-01-EN_PDF_CERAMICCAPACITORSMD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
C68 | 100n/50V | Murata | GRM21BR71H104KA01L | Capacitor_SMD:C_0805_2012Metric | https://pim.murata.com/asset/pim4/ceramicCapacitorSMD/GRM21BR71H104KA01-01-EN_PDF_CERAMICCAPACITORSMD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
R50 | 4.7k | Yageo | RC0805FR-074K7L | Resistor_SMD:R_0805_2012Metric | https://www.yageo.com/en/Chart/Download/pdf/RC0805
D11 | BAT54 | Nexperia | BAT54,215 | Package_TO_SOT_SMD:SOT-23 | https://assets.nexperia.com/documents/data-sheet/BAT54_SER.pdf | Reset also clears gate-enable latch
D12 | BAT54 | Nexperia | BAT54,215 | Package_TO_SOT_SMD:SOT-23 | https://assets.nexperia.com/documents/data-sheet/BAT54_SER.pdf | 12 V power-good failure also clears gate-enable latch
J6 | STOP / external open-drain fault | Samtec | TSW-002-07-G-S | Connector_PinHeader_2.54mm:PinHeader_1x02_P2.54mm_Vertical | https://www.samtec.com/products/tsw | STOP / external open-drain fault
U12 | SN74LVC1G74DCTR | Texas Instruments | SN74LVC1G74DCTR | Package_SO:SSOP-8_2.95x2.8mm_P0.65mm | https://www.ti.com/lit/ds/symlink/sn74lvc1g74.pdf
U13 | SN74LVC1G86DBVR | Texas Instruments | SN74LVC1G86DBVR | Package_TO_SOT_SMD:SOT-23-5 | https://www.ti.com/lit/ds/symlink/sn74lvc1g86.pdf
U14 | SN74LVC1G08DBVR | Texas Instruments | SN74LVC1G08DBVR | Package_TO_SOT_SMD:SOT-23-5 | https://www.ti.com/lit/ds/symlink/sn74lvc1g08.pdf
U15 | SN74LVC2G08DCTR | Texas Instruments | SN74LVC2G08DCTR | Package_SO:SSOP-8_2.95x2.8mm_P0.65mm | https://www.ti.com/lit/ds/symlink/sn74lvc2g08.pdf
R51 | 33 | Yageo | RC0805FR-0733RL | Resistor_SMD:R_0805_2012Metric | https://www.yageo.com/en/Chart/Download/pdf/RC0805
R52 | 33 | Yageo | RC0805FR-0733RL | Resistor_SMD:R_0805_2012Metric | https://www.yageo.com/en/Chart/Download/pdf/RC0805
R53 | 10k | Yageo | RC0805FR-0710KL | Resistor_SMD:R_0805_2012Metric | https://www.yageo.com/en/Chart/Download/pdf/RC0805
R54 | 10k | Yageo | RC0805FR-0710KL | Resistor_SMD:R_0805_2012Metric | https://www.yageo.com/en/Chart/Download/pdf/RC0805
R55 | 10k | Yageo | RC0805FR-0710KL | Resistor_SMD:R_0805_2012Metric | https://www.yageo.com/en/Chart/Download/pdf/RC0805
C69 | 100n/50V | Murata | GRM21BR71H104KA01L | Capacitor_SMD:C_0805_2012Metric | https://pim.murata.com/asset/pim4/ceramicCapacitorSMD/GRM21BR71H104KA01-01-EN_PDF_CERAMICCAPACITORSMD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
C70 | 100n/50V | Murata | GRM21BR71H104KA01L | Capacitor_SMD:C_0805_2012Metric | https://pim.murata.com/asset/pim4/ceramicCapacitorSMD/GRM21BR71H104KA01-01-EN_PDF_CERAMICCAPACITORSMD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
C71 | 100n/50V | Murata | GRM21BR71H104KA01L | Capacitor_SMD:C_0805_2012Metric | https://pim.murata.com/asset/pim4/ceramicCapacitorSMD/GRM21BR71H104KA01-01-EN_PDF_CERAMICCAPACITORSMD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
C72 | 100n/50V | Murata | GRM21BR71H104KA01L | Capacitor_SMD:C_0805_2012Metric | https://pim.murata.com/asset/pim4/ceramicCapacitorSMD/GRM21BR71H104KA01-01-EN_PDF_CERAMICCAPACITORSMD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
U16 | TMS320F28335PGFA | Texas Instruments | TMS320F28335PGFA | Package_QFP:LQFP-176_24x24mm_P0.5mm | https://www.ti.com/lit/ds/symlink/tms320f28335.pdf
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

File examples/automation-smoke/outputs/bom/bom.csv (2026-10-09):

Refs | Value | Footprint | Qty | DNP
J1 | VIN_VOUT_GND | Connector_PinHeader_2.54mm:PinHeader_1x03_P2.54mm_Vertical | 1
R1 | 10k | Resistor_SMD:R_0805_2012Metric | 1
R2 | 10k | Resistor_SMD:R_0805_2012Metric | 1

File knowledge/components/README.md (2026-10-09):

# Component knowledge

Records here capture **design knowledge about parts used in reference
designs**: why a part was used, the parameters that matter for that use (with
the datasheet or reference location they came from), application conditions,
design considerations and only those alternatives that a cited source names.
They are not a parametric catalogue and do not duplicate the AIPE Transistor
Database.

## Integration with existing AIPE databases

Each record has:

```json
"external_refs": {"aipe_component_db": null, "aipe_transistor_db": null}
```

Set these to the corresponding database keys when the databases are connected.
An integration adapter should:

1. look up `part_number` and `orderable_variants` in the AIPE database;
2. fill `external_refs` with the matching key (never overwrite a non-null key
   without review);
3. keep parametric data in the database and design knowledge here; the
   retrieval API returns both ids so an agent can join them.

Power semiconductors from the references (C3M0075120K, C3M0030090K, the
Wolfspeed modules cited in PRD-09301) intentionally have no records here; they
belong to the Transistor Database.

## Datasheet status

`datasheet.url_status` is `verified-pdf` only when the URL was downloaded and
the content was a PDF (`datasheet.acquisition` holds date, size and SHA-256).
`unverified` means a manufacturer URL is recorded but could not be confirmed;
`not-located` means no official URL was found and parameters come from the
reference documents only.

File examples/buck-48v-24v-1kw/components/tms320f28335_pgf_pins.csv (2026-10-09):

pin | name | source
1 | GPIO30 | TI SPRS439Q Table 6-1 pages 22-31; PGF column
2 | GPIO29 | TI SPRS439Q Table 6-1 pages 22-31; PGF column
3 | VSS | TI SPRS439Q Table 6-1 pages 22-31; PGF column
4 | VDD | TI SPRS439Q Table 6-1 pages 22-31; PGF column
5 | GPIO0 | TI SPRS439Q Table 6-1 pages 22-31; PGF column
6 | GPIO1 | TI SPRS439Q Table 6-1 pages 22-31; PGF column
7 | GPIO2 | TI SPRS439Q Table 6-1 pages 22-31; PGF column
8 | VSS | TI SPRS439Q Table 6-1 pages 22-31; PGF column
9 | VDDIO | TI SPRS439Q Table 6-1 pages 22-31; PGF column
10 | GPIO3 | TI SPRS439Q Table 6-1 pages 22-31; PGF column
11 | GPIO4 | TI SPRS439Q Table 6-1 pages 22-31; PGF column
12 | GPIO5 | TI SPRS439Q Table 6-1 pages 22-31; PGF column
13 | GPIO6 | TI SPRS439Q Table 6-1 pages 22-31; PGF column
14 | VSS | TI SPRS439Q Table 6-1 pages 22-31; PGF column
15 | VDD | TI SPRS439Q Table 6-1 pages 22-31; PGF column
16 | GPIO7 | TI SPRS439Q Table 6-1 pages 22-31; PGF column
17 | GPIO8 | TI SPRS439Q Table 6-1 pages 22-31; PGF column
18 | GPIO9 | TI SPRS439Q Table 6-1 pages 22-31; PGF column
19 | GPIO10 | TI SPRS439Q Table 6-1 pages 22-31; PGF column
20 | GPIO11 | TI SPRS439Q Table 6-1 pages 22-31; PGF column
21 | GPIO12 | TI SPRS439Q Table 6-1 pages 22-31; PGF column
22 | VSS | TI SPRS439Q Table 6-1 pages 22-31; PGF column
23 | VDD | TI SPRS439Q Table 6-1 pages 22-31; PGF column
24 | GPIO13 | TI SPRS439Q Table 6-1 pages 22-31; PGF column
25 | GPIO14 | TI SPRS439Q Table 6-1 pages 22-31; PGF column
26 | GPIO15 | TI SPRS439Q Table 6-1 pages 22-31; PGF column
27 | GPIO16 | TI SPRS439Q Table 6-1 pages 22-31; PGF column
28 | GPIO17 | TI SPRS439Q Table 6-1 pages 22-31; PGF column
29 | VDD | TI SPRS439Q Table 6-1 pages 22-31; PGF column
30 | VSS | TI SPRS439Q Table 6-1 pages 22-31; PGF column
31 | VDD1A18 | TI SPRS439Q Table 6-1 pages 22-31; PGF column
32 | VSS1AGND | TI SPRS439Q Table 6-1 pages 22-31; PGF column
33 | VSSA2 | TI SPRS439Q Table 6-1 pages 22-31; PGF column
34 | VDDA2 | TI SPRS439Q Table 6-1 pages 22-31; PGF column
35 | ADCINA7 | TI SPRS439Q Table 6-1 pages 22-31; PGF column
36 | ADCINA6 | TI SPRS439Q Table 6-1 pages 22-31; PGF column
37 | ADCINA5 | TI SPRS439Q Table 6-1 pages 22-31; PGF column
38 | ADCINA4 | TI SPRS439Q Table 6-1 pages 22-31; PGF column
39 | ADCINA3 | TI SPRS439Q Table 6-1 pages 22-31; PGF column
40 | ADCINA2 | TI SPRS439Q Table 6-1 pages 22-31; PGF column
41 | ADCINA1 | TI SPRS439Q Table 6-1 pages 22-31; PGF column
42 | ADCINA0 | TI SPRS439Q Table 6-1 pages 22-31; PGF column
43 | ADCLO | TI SPRS439Q Table 6-1 pages 22-31; PGF column
44 | VSSAIO | TI SPRS439Q Table 6-1 pages 22-31; PGF column
45 | VDDAIO | TI SPRS439Q Table 6-1 pages 22-31; PGF column
46 | ADCINB0 | TI SPRS439Q Table 6-1 pages 22-31; PGF column
47 | ADCINB1 | TI SPRS439Q Table 6-1 pages 22-31; PGF column
48 | ADCINB2 | TI SPRS439Q Table 6-1 pages 22-31; PGF column
49 | ADCINB3 | TI SPRS439Q Table 6-1 pages 22-31; PGF column
50 | ADCINB4 | TI SPRS439Q Table 6-1 pages 22-31; PGF column
51 | ADCINB5 | TI SPRS439Q Table 6-1 pages 22-31; PGF column
52 | ADCINB6 | TI SPRS439Q Table 6-1 pages 22-31; PGF column
53 | ADCINB7 | TI SPRS439Q Table 6-1 pages 22-31; PGF column
54 | ADCREFIN | TI SPRS439Q Table 6-1 pages 22-31; PGF column
55 | ADCREFM | TI SPRS439Q Table 6-1 pages 22-31; PGF column
56 | ADCREFP | TI SPRS439Q Table 6-1 pages 22-31; PGF column
57 | ADCRESEXT | TI SPRS439Q Table 6-1 pages 22-31; PGF column
58 | VSS2AGND | TI SPRS439Q Table 6-1 pages 22-31; PGF column
59 | VDD2A18 | TI SPRS439Q Table 6-1 pages 22-31; PGF column
60 | VSS | TI SPRS439Q Table 6-1 pages 22-31; PGF column
61 | VDD | TI SPRS439Q Table 6-1 pages 22-31; PGF column
62 | GPIO18 | TI SPRS439Q Table 6-1 pages 22-31; PGF column
63 | GPIO19 | TI SPRS439Q Table 6-1 pages 22-31; PGF column
64 | GPIO20 | TI SPRS439Q Table 6-1 pages 22-31; PGF column
65 | GPIO21 | TI SPRS439Q Table 6-1 pages 22-31; PGF column
66 | GPIO22 | TI SPRS439Q Table 6-1 pages 22-31; PGF column
67 | GPIO23 | TI SPRS439Q Table 6-1 pages 22-31; PGF column
68 | GPIO24 | TI SPRS439Q Table 6-1 pages 22-31; PGF column
69 | GPIO25 | TI SPRS439Q Table 6-1 pages 22-31; PGF column
70 | VSS | TI SPRS439Q Table 6-1 pages 22-31; PGF column
71 | VDDIO | TI SPRS439Q Table 6-1 pages 22-31; PGF column
72 | GPIO26 | TI SPRS439Q Table 6-1 pages 22-31; PGF column
73 | GPIO27 | TI SPRS439Q Table 6-1 pages 22-31; PGF column
74 | GPIO32 | TI SPRS439Q Table 6-1 pages 22-31; PGF column
75 | GPIO33 | TI SPRS439Q Table 6-1 pages 22-31; PGF column
76 | TDI | TI SPRS439Q Table 6-1 pages 22-31; PGF column
77 | TDO | TI SPRS439Q Table 6-1 pages 22-31; PGF column
78 | TRST | TI SPRS439Q Table 6-1 pages 22-31; PGF column
79 | TMS | TI SPRS439Q Table 6-1 pages 22-31; PGF column
80 | XRS | TI SPRS439Q Table 6-1 pages 22-31; PGF column
81 | TEST1 | TI SPRS439Q Table 6-1 pages 22-31; PGF column
82 | TEST2 | TI SPRS439Q Table 6-1 pages 22-31; PGF column
83 | VSS | TI SPRS439Q Table 6-1 pages 22-31; PGF column
84 | VDD3VFL | TI SPRS439Q Table 6-1 pages 22-31; PGF column
85 | EMU0 | TI SPRS439Q Table 6-1 pages 22-31; PGF column
86 | EMU1 | TI SPRS439Q Table 6-1 pages 22-31; PGF column
87 | TCK | TI SPRS439Q Table 6-1 pages 22-31; PGF column
88 | GPIO48 | TI SPRS439Q Table 6-1 pages 22-31; PGF column
89 | GPIO49 | TI SPRS439Q Table 6-1 pages 22-31; PGF column
90 | GPIO50 | TI SPRS439Q Table 6-1 pages 22-31; PGF column
91 | GPIO51 | TI SPRS439Q Table 6-1 pages 22-31; PGF column
92 | VSS | TI SPRS439Q Table 6-1 pages 22-31; PGF column
93 | VDDIO | TI SPRS439Q Table 6-1 pages 22-31; PGF column
94 | GPIO52 | TI SPRS439Q Table 6-1 pages 22-31; PGF column
95 | GPIO53 | TI SPRS439Q Table 6-1 pages 22-31; PGF column
96 | GPIO54 | TI SPRS439Q Table 6-1 pages 22-31; PGF column
97 | GPIO55 | TI SPRS439Q Table 6-1 pages 22-31; PGF column
98 | GPIO56 | TI SPRS439Q Table 6-1 pages 22-31; PGF column
99 | GPIO57 | TI SPRS439Q Table 6-1 pages 22-31; PGF column
100 | GPIO58 | TI SPRS439Q Table 6-1 pages 22-31; PGF column
101 | VDD | TI SPRS439Q Table 6-1 pages 22-31; PGF column
102 | X2 | TI SPRS439Q Table 6-1 pages 22-31; PGF column
103 | VSS | TI SPRS439Q Table 6-1 pages 22-31; PGF column
104 | X1 | TI SPRS439Q Table 6-1 pages 22-31; PGF column
105 | XCLKIN | TI SPRS439Q Table 6-1 pages 22-31; PGF column
106 | VSS | TI SPRS439Q Table 6-1 pages 22-31; PGF column
107 | VDDIO | TI SPRS439Q Table 6-1 pages 22-31; PGF column
108 | VSS | TI SPRS439Q Table 6-1 pages 22-31; PGF column
109 | VDD | TI SPRS439Q Table 6-1 pages 22-31; PGF column
110 | GPIO59 | TI SPRS439Q Table 6-1 pages 22-31; PGF column
111 | GPIO60 | TI SPRS439Q Table 6-1 pages 22-31; PGF column
112 | GPIO61 | TI SPRS439Q Table 6-1 pages 22-31; PGF column
113 | GPIO62 | TI SPRS439Q Table 6-1 pages 22-31; PGF column
114 | GPIO63 | TI SPRS439Q Table 6-1 pages 22-31; PGF column
115 | GPIO64 | TI SPRS439Q Table 6-1 pages 22-31; PGF column
116 | GPIO65 | TI SPRS439Q Table 6-1 pages 22-31; PGF column
117 | VDD | TI SPRS439Q Table 6-1 pages 22-31; PGF column
118 | VSS | TI SPRS439Q Table 6-1 pages 22-31; PGF column
119 | GPIO66 | TI SPRS439Q Table 6-1 pages 22-31; PGF column
120 | VSS | TI SPRS439Q Table 6-1 pages 22-31; PGF column
121 | VDDIO | TI SPRS439Q Table 6-1 pages 22-31; PGF column
122 | GPIO67 | TI SPRS439Q Table 6-1 pages 22-31; PGF column
123 | GPIO68 | TI SPRS439Q Table 6-1 pages 22-31; PGF column
124 | GPIO69 | TI SPRS439Q Table 6-1 pages 22-31; PGF column
125 | VSS | TI SPRS439Q Table 6-1 pages 22-31; PGF column
126 | VDD | TI SPRS439Q Table 6-1 pages 22-31; PGF column
127 | GPIO70 | TI SPRS439Q Table 6-1 pages 22-31; PGF column
128 | GPIO71 | TI SPRS439Q Table 6-1 pages 22-31; PGF column
129 | GPIO72 | TI SPRS439Q Table 6-1 pages 22-31; PGF column
130 | GPIO73 | TI SPRS439Q Table 6-1 pages 22-31; PGF column
131 | GPIO74 | TI SPRS439Q Table 6-1 pages 22-31; PGF column
132 | GPIO75 | TI SPRS439Q Table 6-1 pages 22-31; PGF column
133 | GPIO76 | TI SPRS439Q Table 6-1 pages 22-31; PGF column
134 | GPIO77 | TI SPRS439Q Table 6-1 pages 22-31; PGF column
135 | GPIO78 | TI SPRS439Q Table 6-1 pages 22-31; PGF column
136 | GPIO79 | TI SPRS439Q Table 6-1 pages 22-31; PGF column
137 | GPIO38 | TI SPRS439Q Table 6-1 pages 22-31; PGF column
138 | XCLKOUT | TI SPRS439Q Table 6-1 pages 22-31; PGF column
139 | VDD | TI SPRS439Q Table 6-1 pages 22-31; PGF column
140 | VSS | TI SPRS439Q Table 6-1 pages 22-31; PGF column
141 | GPIO28 | TI SPRS439Q Table 6-1 pages 22-31; PGF column
142 | GPIO34 | TI SPRS439Q Table 6-1 pages 22-31; PGF column
143 | VDDIO | TI SPRS439Q Table 6-1 pages 22-31; PGF column
144 | VSS | TI SPRS439Q Table 6-1 pages 22-31; PGF column
145 | GPIO36 | TI SPRS439Q Table 6-1 pages 22-31; PGF column
146 | VDD | TI SPRS439Q Table 6-1 pages 22-31; PGF column
147 | VSS | TI SPRS439Q Table 6-1 pages 22-31; PGF column
148 | GPIO35 | TI SPRS439Q Table 6-1 pages 22-31; PGF column
149 | XRD | TI SPRS439Q Table 6-1 pages 22-31; PGF column
150 | GPIO37 | TI SPRS439Q Table 6-1 pages 22-31; PGF column
151 | GPIO40 | TI SPRS439Q Table 6-1 pages 22-31; PGF column
152 | GPIO41 | TI SPRS439Q Table 6-1 pages 22-31; PGF column
153 | GPIO42 | TI SPRS439Q Table 6-1 pages 22-31; PGF column
154 | VDD | TI SPRS439Q Table 6-1 pages 22-31; PGF column
155 | VSS | TI SPRS439Q Table 6-1 pages 22-31; PGF column
156 | GPIO43 | TI SPRS439Q Table 6-1 pages 22-31; PGF column
157 | GPIO44 | TI SPRS439Q Table 6-1 pages 22-31; PGF column
158 | GPIO45 | TI SPRS439Q Table 6-1 pages 22-31; PGF column
159 | VDDIO | TI SPRS439Q Table 6-1 pages 22-31; PGF column
160 | VSS | TI SPRS439Q Table 6-1 pages 22-31; PGF column
161 | GPIO46 | TI SPRS439Q Table 6-1 pages 22-31; PGF column
162 | GPIO47 | TI SPRS439Q Table 6-1 pages 22-31; PGF column
163 | GPIO80 | TI SPRS439Q Table 6-1 pages 22-31; PGF column
164 | GPIO81 | TI SPRS439Q Table 6-1 pages 22-31; PGF column
165 | GPIO82 | TI SPRS439Q Table 6-1 pages 22-31; PGF column
166 | VSS | TI SPRS439Q Table 6-1 pages 22-31; PGF column
167 | VDD | TI SPRS439Q Table 6-1 pages 22-31; PGF column
168 | GPIO83 | TI SPRS439Q Table 6-1 pages 22-31; PGF column
169 | GPIO84 | TI SPRS439Q Table 6-1 pages 22-31; PGF column
170 | VDDIO | TI SPRS439Q Table 6-1 pages 22-31; PGF column
171 | VSS | TI SPRS439Q Table 6-1 pages 22-31; PGF column
172 | GPIO85 | TI SPRS439Q Table 6-1 pages 22-31; PGF column
173 | GPIO86 | TI SPRS439Q Table 6-1 pages 22-31; PGF column
174 | GPIO87 | TI SPRS439Q Table 6-1 pages 22-31; PGF column
175 | GPIO39 | TI SPRS439Q Table 6-1 pages 22-31; PGF column
176 | GPIO31 | TI SPRS439Q Table 6-1 pages 22-31; PGF column

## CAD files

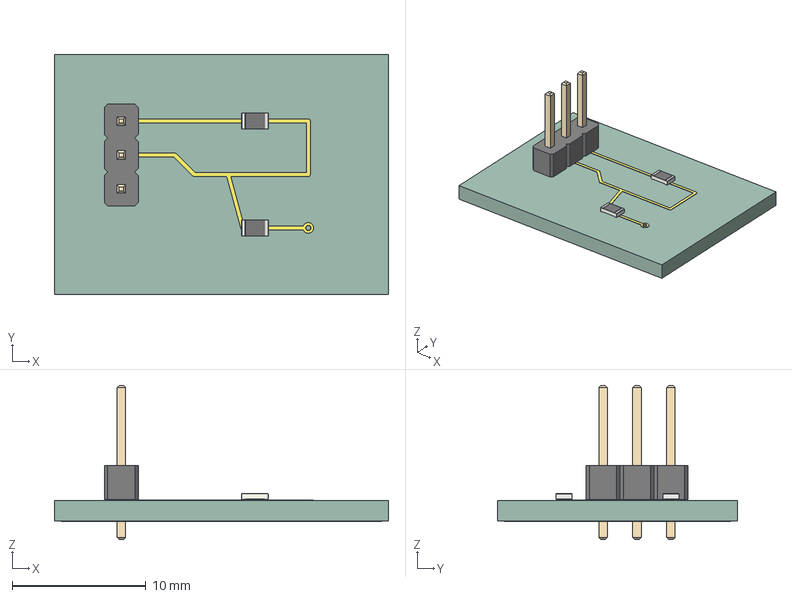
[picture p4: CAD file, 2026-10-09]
examples/automation-smoke/outputs/step/board.step
25.0 x 18.0 x 11.5 mm
PinHeader_1x03_P254mm_Vertical
R_0805_2012Metric x 2
AIPE_Smoke_copper
AIPE_Smoke_via
AIPE_Smoke_PCB

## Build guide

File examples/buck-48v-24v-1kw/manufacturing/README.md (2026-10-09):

# Manufacturing-file review bundle

**AI-GENERATED ENGINEERING PROTOTYPE - V1 - HUMAN REVIEW REQUIRED**

These are generated manufacturing formats for engineering/DFM review. No
fabrication or assembly order is authorized or implied.

- `gerber`: F.Cu, In1.Cu, In2.Cu, In3.Cu, In4.Cu and B.Cu are the six copper
  layers. Mask, paste, silkscreen and Edge.Cuts are separate outputs. F.Fab is
  an assembly/reference drawing, not an additional copper layer. Use the
  `.gbrjob` layer metadata rather than inferring stack order alphabetically.
- `drill`: Excellon PTH/NPTH files and the native drill report. Review the
  inductor's plated oval slots, bolt holes and exposed-pad via treatment.
- `bom/purchasing_bom.csv`: 220 electronic components with manufacturer/MPN.
  `bom/bom.csv` is KiCad's native schematic export. Mounting holes/test pads
  are bare PCB features; mechanical hardware is not a completed purchasing BOM.
- `pick_and_place`: Native coordinate export in mm. Separate SMT/THT/manual
  operations and verify origin/rotation with an assembler before using it.
- `step`: Populated board with tracks/zones and dimensioned custom envelopes.
  Heatsinks, cables, clamps, hardware and exact vendor mechanical details are
  not a validated assembly. STEP export was checked for missing-model messages.
- `review`: Source PDF and PNG exports, also copied to the example's review
  entry point. The F.Fab PDF page supplies component designators.
- `logs` and `export-manifest.json`: Actual CLI command outcomes, input-source
  hashes and output hashes. Additional purchasing/README files are covered by
  the frozen release manifest rather than the original export manifest.

Build requirements and constraints are in `../design/pcb_stackup.md`; unresolved
engineering issues are in `../verification/known_issues.md`. The six-layer,
heavy-copper/fine-pitch combination needs fabricator agreement before ordering.

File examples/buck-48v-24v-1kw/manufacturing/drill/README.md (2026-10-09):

# Drill interpretation

The native `AIPE_Buck_1kW.drl` uses KiCad Excellon attributes and combines both
plating types in one file (`TF.FileFunction,MixedPlating,1,6`). Tools T1-T9 are
explicitly marked plated; T10 is explicitly marked non-plated. The native report
counts 834 plated holes (including two plated slots) and eight 3.2 mm NPTH holes.

Do not strip the plating attributes or assume every drill is plated. If the
chosen fabricator requires physically separate files, export the same checked
PCB with `kicad-cli pcb export drill --excellon-separate-th` and review those
outputs before ordering. This is a fabrication-interface decision, not a change
to the frozen board's hole geometry.

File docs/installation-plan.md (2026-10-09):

# Installation proposal

Status: **installed and smoke-tested**. Prepared 2026-10-09, Asia/Shanghai.

| Tool | Finding | Proposed action | Proposed location |
| --- | --- | --- | --- |
| Git 2.53.0.windows.2 | Present | Reuse | Existing installation |
| Python 3.10.11 x64 | Present | Reuse for standard-library automation | Existing installation |
| GitHub CLI 2.88.1 | Present and authenticated | Reuse | Existing installation |
| KiCad 10.0.7 x64 | Not found in PATH, default install roots or installed-app records | Install official stable suite, CLI, symbols, footprints and 3D libraries after confirmation | Proposed D:\EngineeringTools\KiCad\10.0 |
| Additional Python packages | Not currently required by bootstrap | No installation proposed yet | Any future environment and packages require confirmation |
| Third-party KiCad MCP / autorouter | Not required for bootstrap | No installation proposed | None |

Alternative KiCad directory offered: `C:\Program Files\KiCad\10.0`.
The user approved `D:\EngineeringTools\KiCad\10.0`. Installer downloads will
be kept in ignored `.cache/downloads/` inside the repository. Standard installer
settings or user configuration may also be written to the Windows user profile.
Do not change the machine-wide PATH unnecessarily; retain an explicit CLI path
in `.aipe/local-tools.json`.

Before running an installer, verify its official origin and Authenticode
signature. If elevation is necessary, report the exact action requiring user
interaction. Do not silently fall back to a different installation directory.

The official download page reports 10.0.7 as the current stable Windows release.
The exact installed executable and automation capabilities must be verified
locally after installation; web documentation alone is not a smoke test.

References (checked 2026-10-09):

- [KiCad Windows downloads](https://www.kicad.org/download/windows/)
- [KiCad CLI manual](https://docs.kicad.org/10.0/en/cli/cli.html)
- [KiCad API and bindings](https://dev-docs.kicad.org/en/apis-and-binding/)

## Approval record

On 2026-10-09 the user replied "可以" to the explicit request to install the
KiCad 10.0.7 x64 suite, CLI and official libraries at
`D:\EngineeringTools\KiCad\10.0`. This approves that software and location.
Additional dependencies still require separate confirmation. Installation is
complete and verified. The installer exited 0 using current-user mode and the
approved directory. CLI reports 10.0.7; bundled Python 3.11.5 imports `pcbnew`
and reports 10.0.7. Symbols, footprints and 3D libraries are present. Existing
system Python remains 3.10.11.

## Installation evidence

- Download: official download page's Tsinghua mirror, `kicad-10.0.7-x86_64.exe`.
- File size: 968953784 bytes.
- SHA-256 (computed locally): `CE3881B6A9188EB34AC1EBAAEC7651149E8A025206410ADDFB11A1A9656ECF95`.
- Windows Authenticode status: Valid; signer KICAD SERVICES CORPORATION.
- Certificate issuer: GlobalSign GCC R45 EV CodeSigning CA 2020.
- Certificate serial: `39DF6B588D969CA15D8D2756`, matching the official page.
- Install mode: `/S /currentuser /D=D:\EngineeringTools\KiCad\10.0`.
- Executable: `D:\EngineeringTools\KiCad\10.0\bin\kicad-cli.exe`.
- Actual smoke evidence: `examples/automation-smoke/verification/smoke-result.json`.
- No additional application or third-party Python package was installed by the
  automation. The official suite supplies its own Python and dependencies.

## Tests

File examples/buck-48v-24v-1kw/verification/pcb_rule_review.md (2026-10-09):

# V1 power-electronics PCB rule review

Separate review of the final routed CAD. **Human review required.**
Geometry measurements below are automated; their electrical acceptability is not.

| Rule / review question | Evidence and finding | Method / disposition |
|---|---|---|
| PE-PCB-001: Driver distance, gate loop and return | Driver-pad to gate-pad distances {'Q1': 10.796, 'Q2': 8.735, 'Q3': 16.17, 'Q4': 8.816} mm. HO/LO total branched tracks 32.00/59.75 mm. Individual gate resistors exist; high-side return is SW and low-side return GND. Return geometry is not a controlled Kelvin pair. | Semi-automated; ringing, current sharing and propagation review required (V1-01). |
| PE-PCB-002: Are HF capacitors close enough? | Eight 1210 ceramics surround the bridge. Nearest capacitor-to-drain pad distances are 11 mm for Q1/Q2 and 16 mm for Q3/Q4. These distances are long relative to an optimized commutation cell. | Semi-automated; no unconditional acceptance (V1-01). |
| PE-PCB-003: Is commutation loop too large? | Input ceramics, parallel TO-220 devices and copper form a spread-out loop. Native DRC verifies continuity, not loop area or inductance. Source and drain current pass through plated device pins and multiple power layers. | Human review; requires current-loop overlay and field/waveform analysis. |
| PE-PCB-004: Is sensing correctly Kelvin routed? | R9 has four separate nets and no force/sense PCB shorts. ISENSE_P/N track sums are 36.893/45.893 mm; filtered branches are 21.236/21.736 mm. Both 10 ohm input resistors and differential 1 nF capacitor are present. | Automated topology plus human coupling review; not length matched (V1-08). |
| PE-PCB-005: Feedback and switch-node exposure | Main sensing/buffer/ADC routing occupies the right/lower partitions. TEMP_RAW intentionally begins next to the power stage. Extended SW has ground-plane windows; local SW area is about 508/606/546 mm2 on F/In3/B. SW is functional but large. | Semi-automated net bounds; human EMI/return review required. |
| PE-PCB-006: 42 A copper, vias and thermal spreading | Outer 70 um force/output pours; VIN on F/In2; SW on F/In3/B. Each shunt side has 32 x 1.0/0.5 mm vias. Main inductor and MOSFET PTH pads connect multiple layers. Actual shunt-pad necks are narrower than the illustrative 25 mm conductor in calculations. | Geometric inventory; do not apply the 25 mm budget as a whole-board ampacity result. Vendor DFM and thermal analysis required. |
| PE-PCB-007: DSP separation and ground returns | DSP center (181,173) mm versus bridge around (123,49) mm. One common GND net uses In1/In4 and outer pours; no analog/digital split beneath the control area. High-current and signal returns still share impedance. | Semi-automated partition check; reviewer must assess return-current paths. |
| PE-PCB-008: Decoupling placement | 26 dedicated DSP 100 nF bypass capacitors; maximum supply-pin to capacitor-pad distance 6.861 mm. AUX12/bootstrap capacitors are in the driver region. | Semi-automated; longer DSP supply escapes need impedance/settling review. |
| Mechanical: Connectors, inductor and cooling | Four M5 terminals, bolt-down fuse, heavy upright magnetic, eight support holes. Custom power pads reference manufacturer drawings. Heatsink/clamp/cable assembly is not modeled or validated. | Human review required before fabrication (V1-03/09). |

## Conclusion and corrections

The final board has no native DRC errors, warnings, missing connections or schematic-parity findings. A dedicated third SW layer repaired the disconnected power copper; this is a real geometric change, not a DRC waiver. Thermal-via arrays, boot-jumper wiring, package geometry and connector silk were also corrected. The design is suitable for a V1 CAD review, but power-layout, thermal and protection adequacy remain open engineering questions.

Raw measurements: [power-layout-metrics.json](power-layout-metrics.json). Thresholds have not been invented to turn these engineering questions into automatic passes.

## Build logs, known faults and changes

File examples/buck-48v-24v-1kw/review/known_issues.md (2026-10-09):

# V1 known issues and review limits

**AI-GENERATED ENGINEERING PROTOTYPE - V1 - HUMAN REVIEW REQUIRED**

Native ERC/DRC and netlist checks pass. The following engineering issues remain;
a zero CAD finding count does not resolve them.

| ID | Priority | Issue / evidence | Review needed |
|---|---|---|---|
| V1-01 | Before fabrication | Gate and commutation paths are long for a 1 kW switcher: driver-pad distances 8.74-16.17 mm, LO network sum 59.75 mm, ceramic-to-drain distances 11/16 mm | Power engineer review of complete outgoing and return paths; estimate/measure inductance and ringing; determine whether layout revision is required |
| V1-02 | Before energization | 60 A comparator threshold is not guaranteed short-circuit protection; current can rise 8.44 A/us in the conservative fault scenario | Worst-case delay, MOSFET SOA, fuse coordination and source current-limit review; consider a faster dedicated trip strategy |
| V1-03 | Before fabrication | Four live TO-220 tabs, approximately 285 g inductor, fuse bolts and high-current cables need an engineered assembly | Heatsink, insulation, clamp, fastener drawings, torque and clearance review; envelope STEP is insufficient |
| V1-04 | Before fabrication | Input bank has only about 17% summed ripple-rating margin; parallel sharing and capacitor temperature are unknown | Current sharing, cooling, service-life and derating evaluation |
| V1-05 | Before energization | No active inrush, reverse-polarity, prebias, reverse-energy or automotive surge qualification | Restrict initial system requirements to the documented bench-source assumptions; review capacitor charge energy and fuse/TVS coordination |
| V1-06 | Before energization | No validated firmware or compensator; combinational overlap gating has propagation skew | Implement and review the firmware contract, deadtime, startup, synchronous-current policy, trip behavior and loop stability |
| V1-07 | Before energization | Core-first sequence exists, but power-down hold-up, LDO ESR/stability and reset timing have not been measured | Review all ramp/brownout cases, regulator combined thermal limits and actual DSP load |
| V1-08 | Before fabrication | Sense routes are Kelvin-connected but not tightly coupled or length matched; maximum DSP bypass pad distance 6.86 mm | Analog coupling, sample settling and high-frequency decoupling review |
| V1-09 | Before fabrication | Six-layer heavy-copper build contains fine-pitch DSP/logic, plated slots and exposed-pad vias | Fabricator DFM and assembly feedback; confirm mask/paste, plating and via treatment without changing net connectivity |
| V1-10 | Before purchasing | Exact passive order-code availability, MLCC DC-bias curves and some supplier package/lifetime details remain to be confirmed; Taiyo Yuden lists TMK325B7226KMHT as Non-preferred (checked 2026-10-09) | Independent BOM sourcing review; do not substitute by capacitance or footprint alone |
| V1-11 | Performance qualification | Estimated 38.67 W loss / 96.28% efficiency depends on unmeasured transitions, core loss and thermal assumptions | Simulation and measured waveform/temperature validation; no continuous 1 kW rating is established |
| V1-12 | Review handoff | The authenticated GitHub account initially had pull but no push access | Grant write access to the existing repository, push the prepared branch and open the prepared PR |

No fabricated-board, EMC, insulation, lifetime, functional-safety, thermal-rise
or control-loop test results exist. No exclusion/waiver was used to hide an ERC,
DRC or unconnected-net finding. The next design generation requires human
feedback; do not silently alter the frozen V1 files.

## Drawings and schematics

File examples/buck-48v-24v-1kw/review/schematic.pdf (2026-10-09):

1 | 2 | 3 | 4 | 5 | 6 | 7 | 8

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
Size: A3 | Rev: V1 | F Date:
KiCad E.D.A. 10.0.7 | Id: 1/14

# Title: 48 V to 24 V / 1 kW synchronous buck

## File: AIPE_Buck_1kW.kicad_sch

## Sheet: /

## AI-GENERATED ENGINEERING PROTOTYPE - V1 - HUMAN REVIEW REQUIRED

Power path / half bridge / Kelvin shunt 文件: 01_power.kicad_sch 48 V to 12 V auxiliary supply 文件: 04_aux12.kicad_sch Current / voltage / temperature measurement 文件: 07_sensing.kicad_sch F28335 pin assignment - all 176 pins 文件: 10_dsp.kicad_sch Test points and mechanical supports 文件: 13_testpoints.kicad_sch
Input and output bulk capacitor banks 文件: 02_capacitors.kicad_sch | 12 V half-bridge gate driver and gate networks 文件: 03_gate.kicad_sch 12 V to 5 V auxiliary supply 文件: 05_aux5.kicad_sch | 1.9 V / 3.3 V sequencing and reset 文件: 06_dsp_supplies.kicad_sch Hardware comparators and fault collection 文件: 08_protection.kicad_sch | Latched enable and PWM inhibition 文件: 09_pwm_logic.kicad_sch DSP per-pin bypass capacitors 文件: 11_dsp_decoupling.kicad_sch | Clock / ADC reference / boot / JTAG / UART 文件: 12_clock_debug.kicad_sch

# AI-GENERATED ENGINEERING PROTOTYPE - V1 - HUMAN REVIEW REQUIRED

## Design basis: 36-54 V input / 24 V 41.67 A / 100 kHz / 150 MHz F28335

Hardware review prototype. Firmware control loop and thermal performance are unvalidated. All inter-page connections use explicit global net labels. GND is one continuous electrical net.

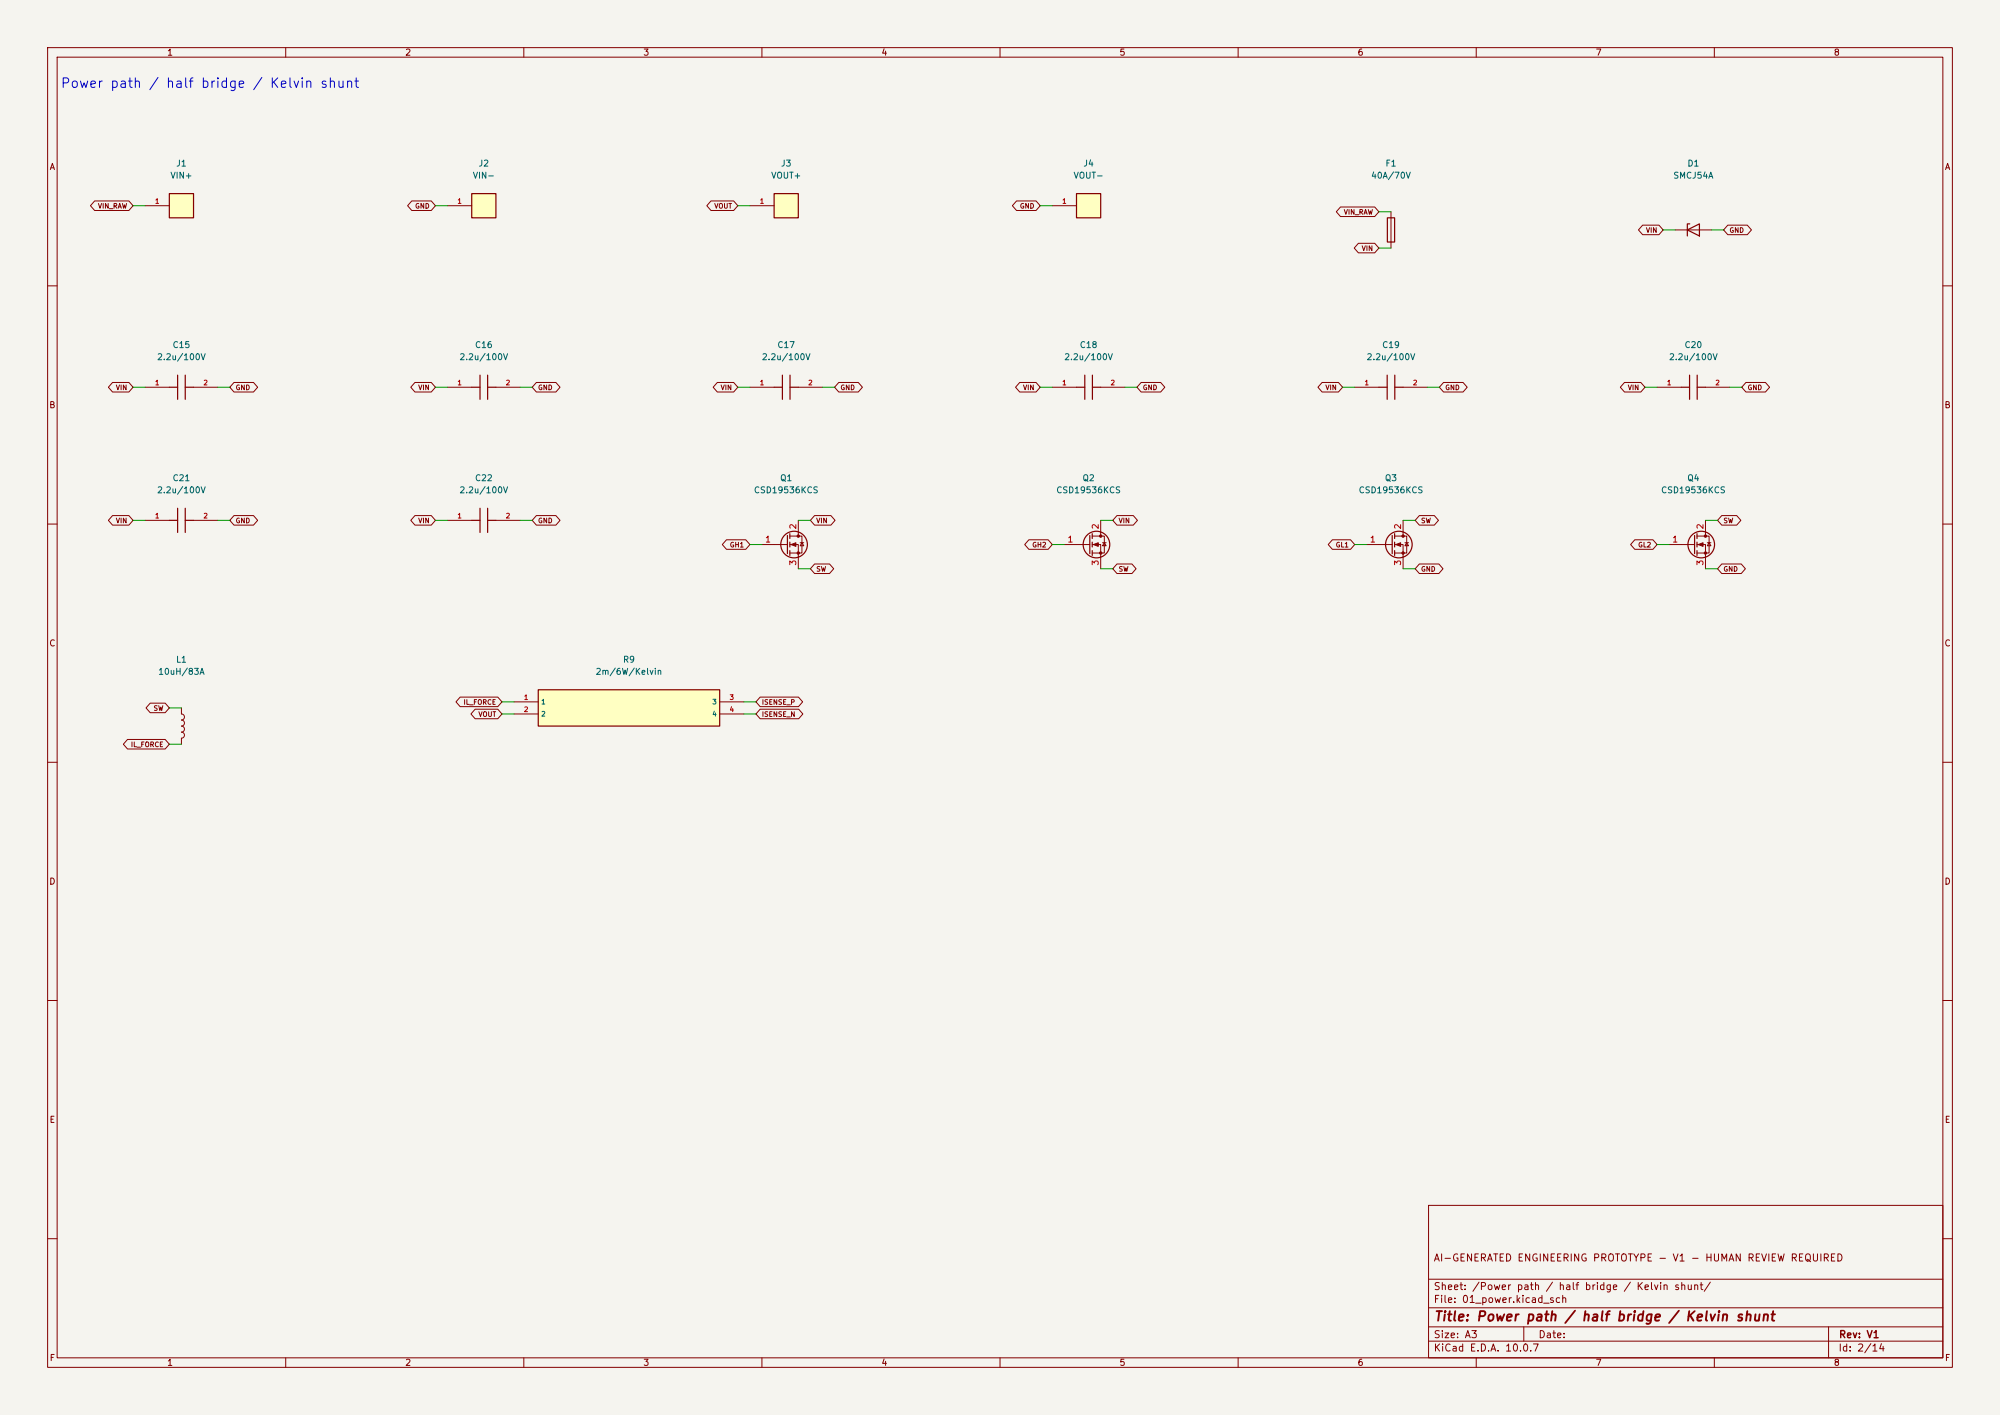
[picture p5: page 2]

SW Power path / half bridge / Kelvin shunt

AI-GENERATED ENGINEERING PROTOTYPE - V1 - HUMAN REVIEW REQUIRED

Sheet: /Power path / half bridge / Kelvin shunt/
File: 01_power.kicad_sch
Title: Power path / half bridge / Kelvin shunt

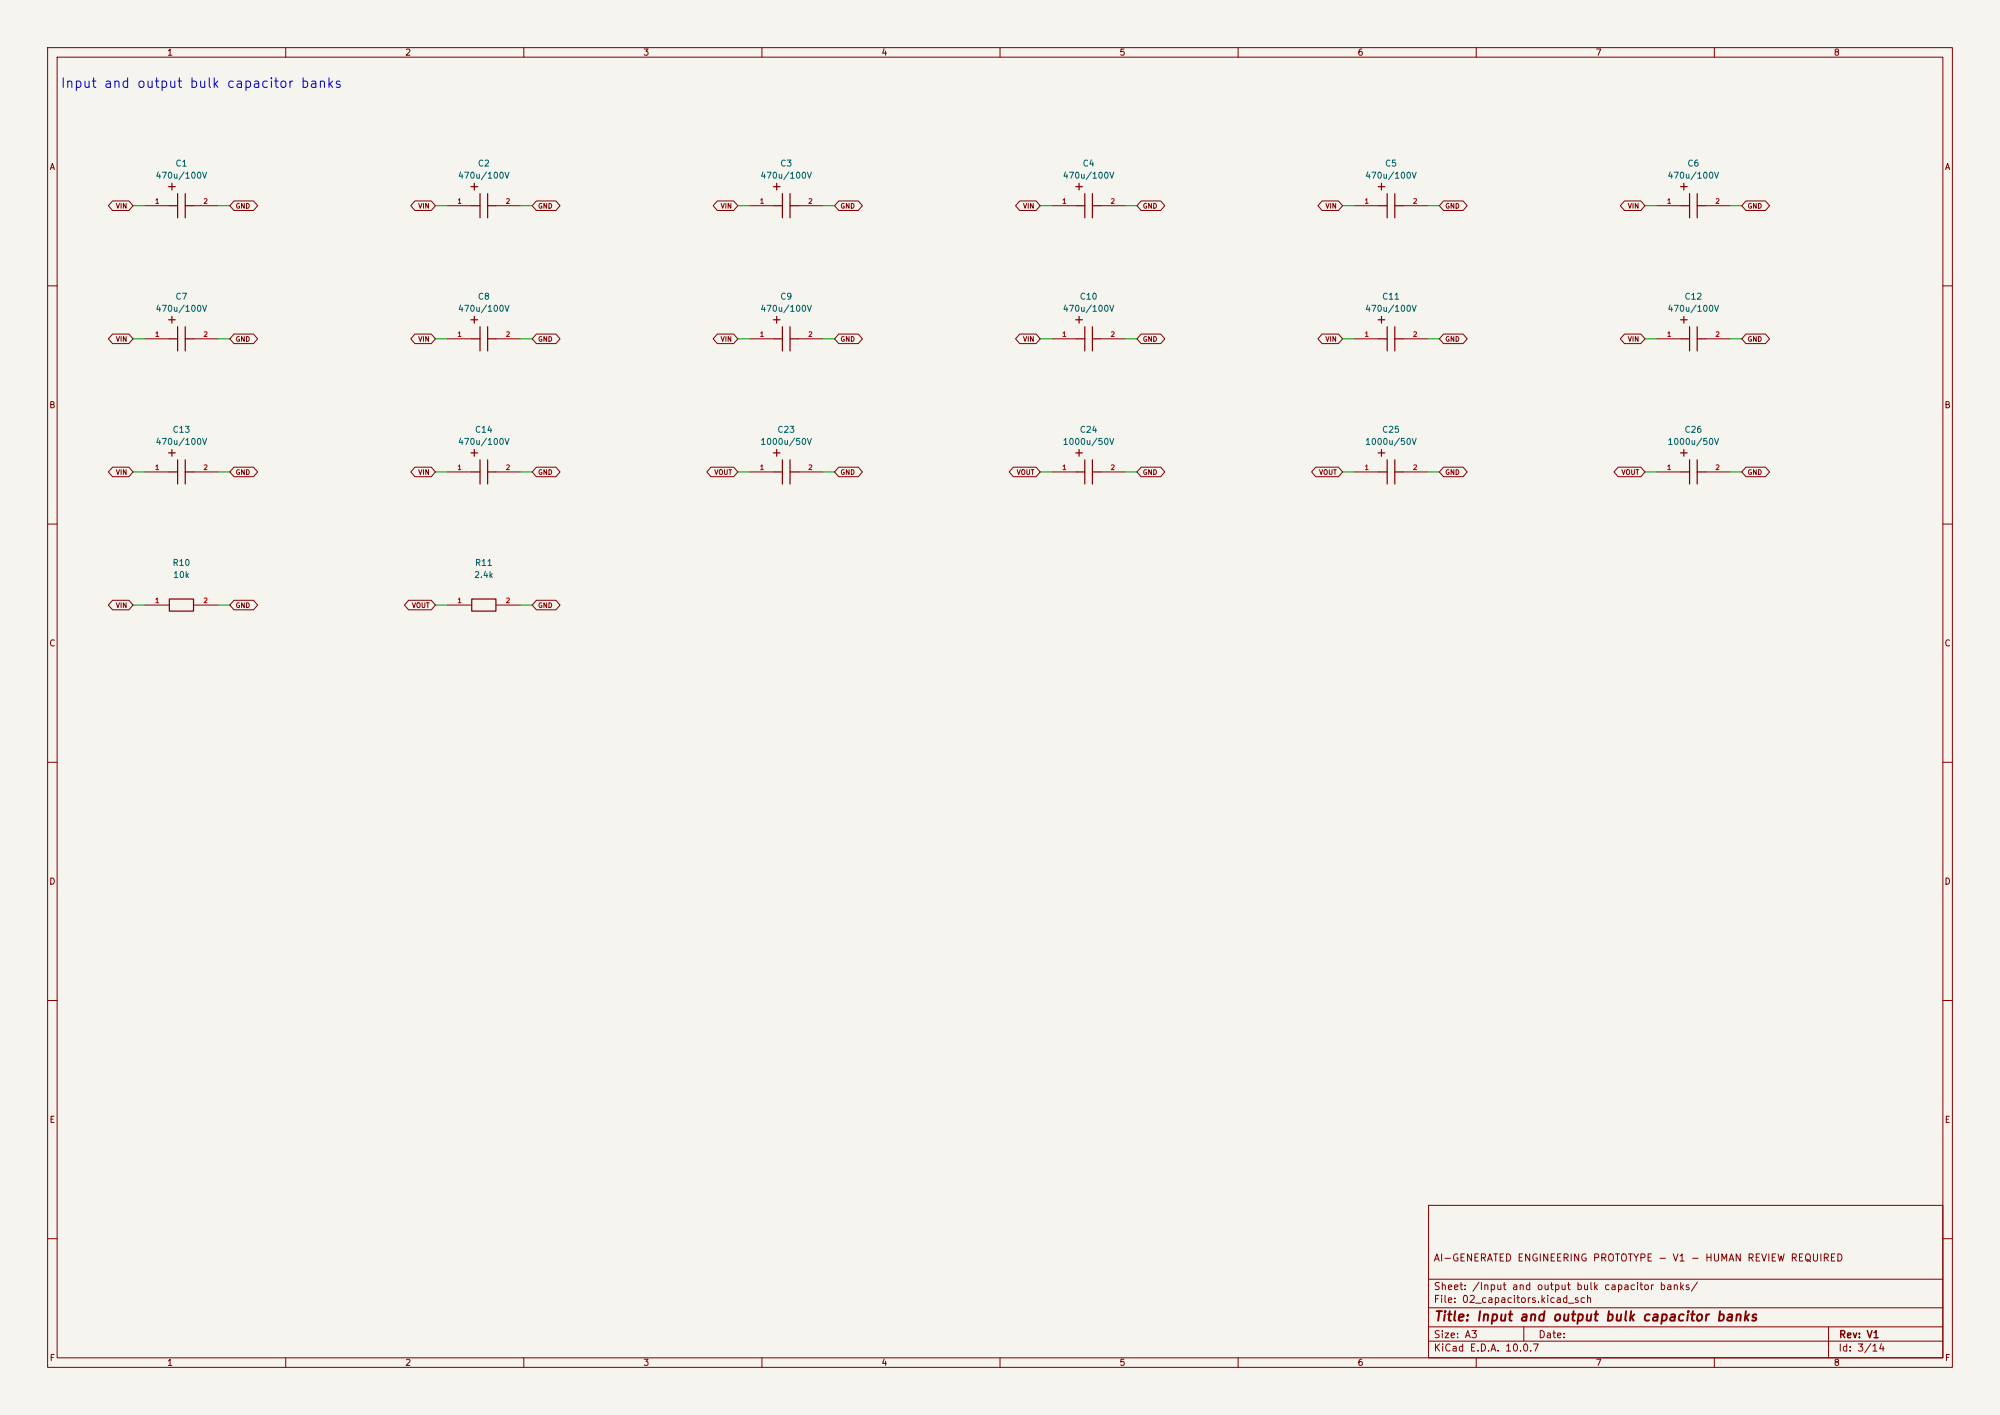
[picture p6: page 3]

Input and output bulk capacitor banks

AI-GENERATED ENGINEERING PROTOTYPE - V1 - HUMAN REVIEW REQUIRED

Sheet: /Input and output bulk capacitor banks/
File: 02_capacitors.kicad_sch
Title: Input and output bulk capacitor banks

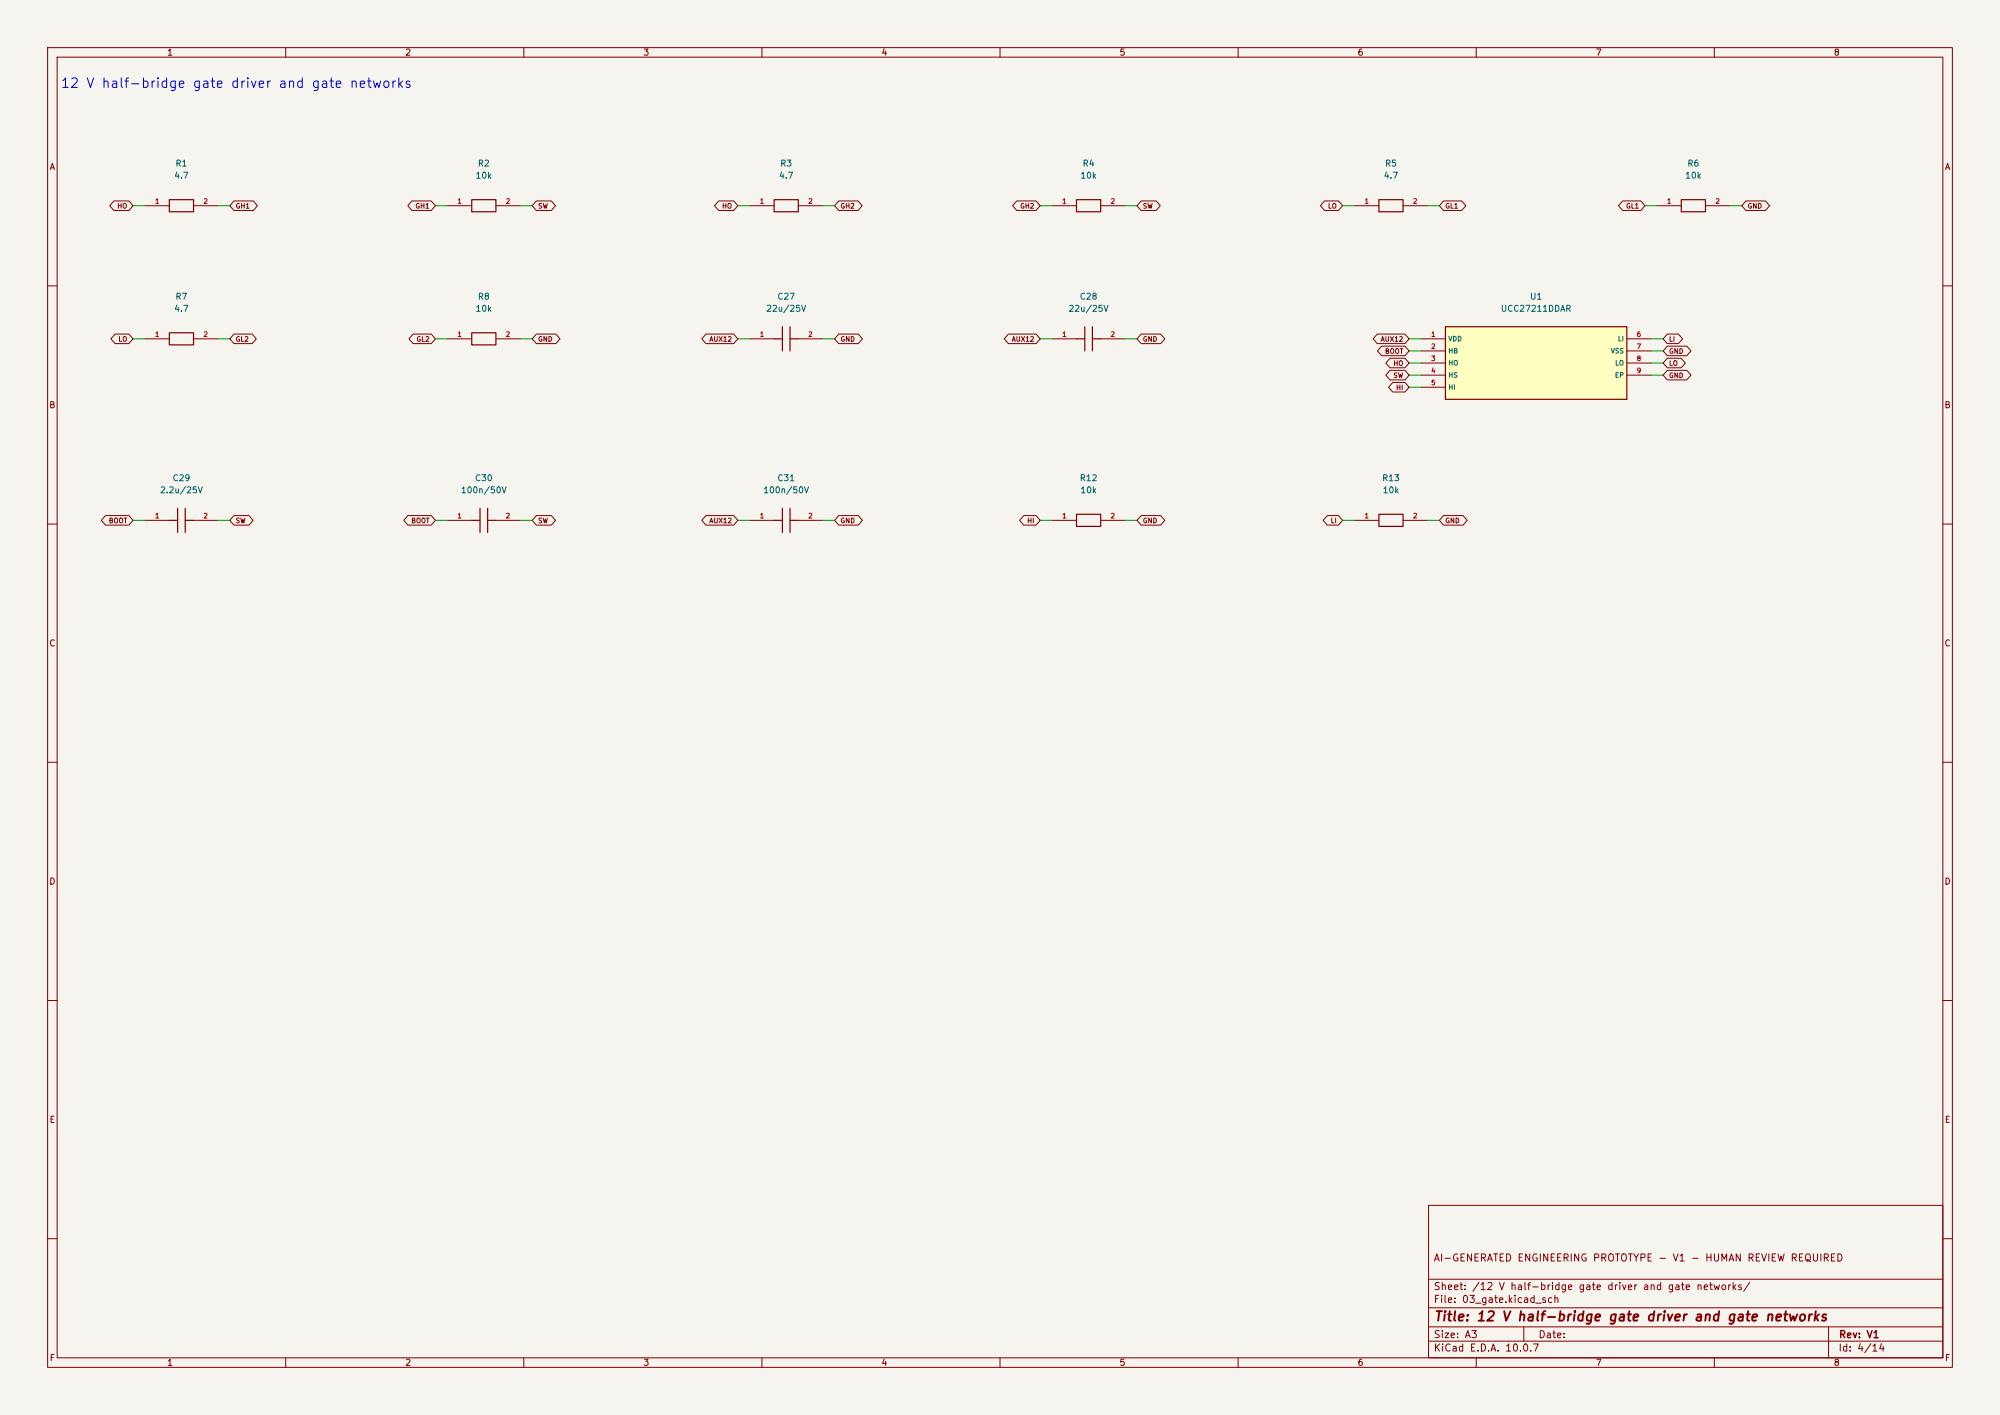
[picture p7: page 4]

LI GND 12 V half-bridge gate driver and gate networks

AI-GENERATED ENGINEERING PROTOTYPE - V1 - HUMAN REVIEW REQUIRED

Sheet: /12 V half-bridge gate driver and gate networks/
File: 03_gate.kicad_sch
Title: 12 V half-bridge gate driver and gate networks

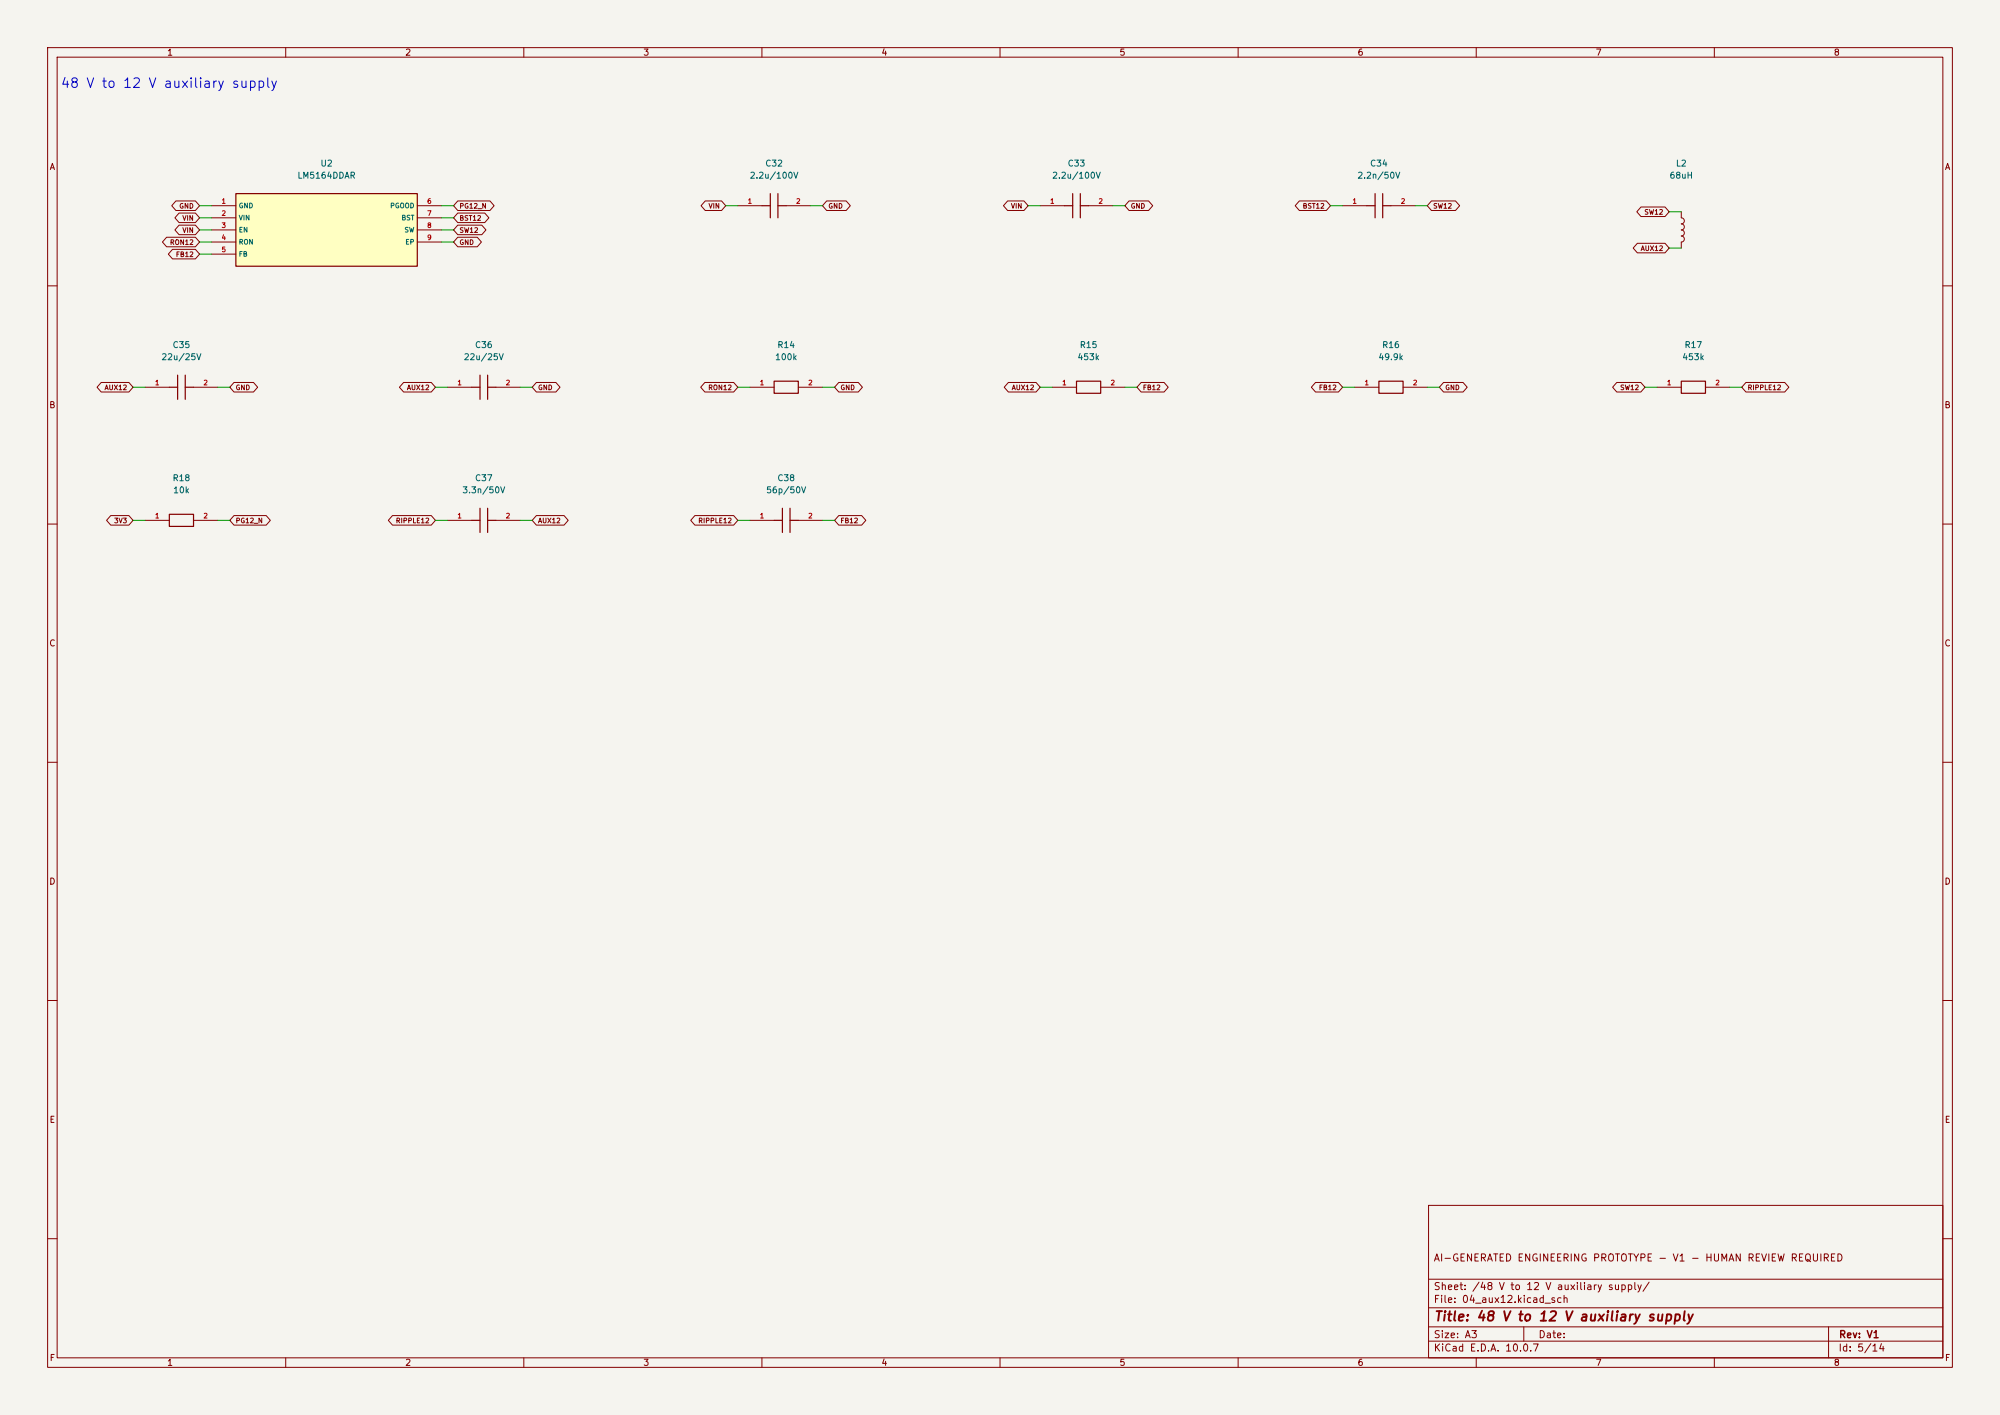
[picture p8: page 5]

AI-GENERATED ENGINEERING PROTOTYPE - V1 - HUMAN REVIEW REQUIRED

Sheet: /48 V to 12 V auxiliary supply/
File: 04_aux12.kicad_sch
Title: 48 V to 12 V auxiliary supply

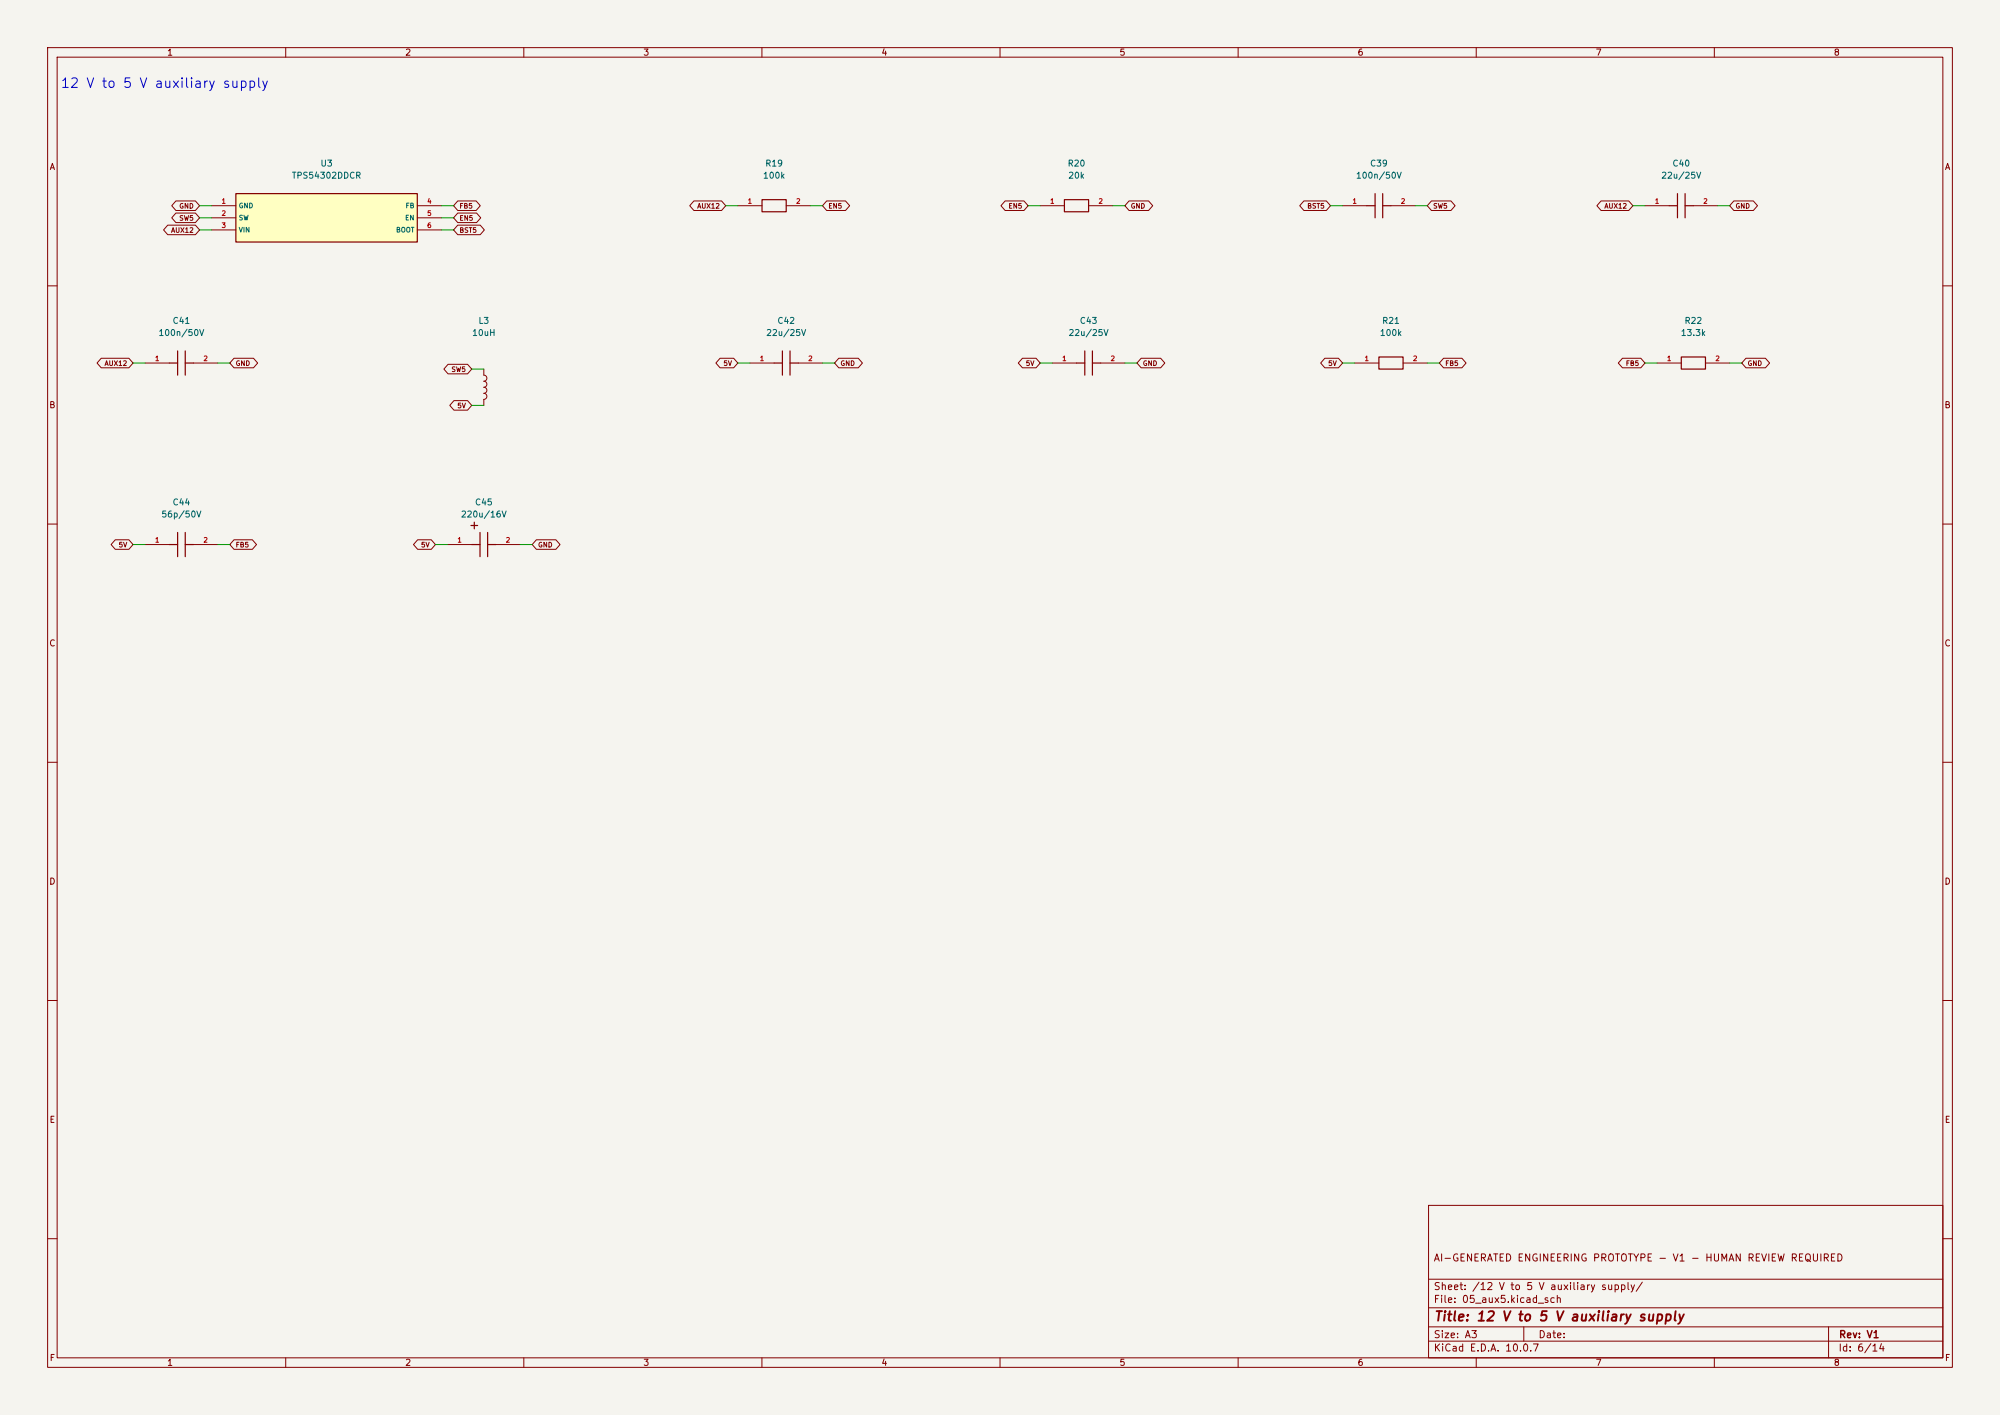
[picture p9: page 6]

AI-GENERATED ENGINEERING PROTOTYPE - V1 - HUMAN REVIEW REQUIRED

Sheet: /12 V to 5 V auxiliary supply/
File: 05_aux5.kicad_sch
Title: 12 V to 5 V auxiliary supply

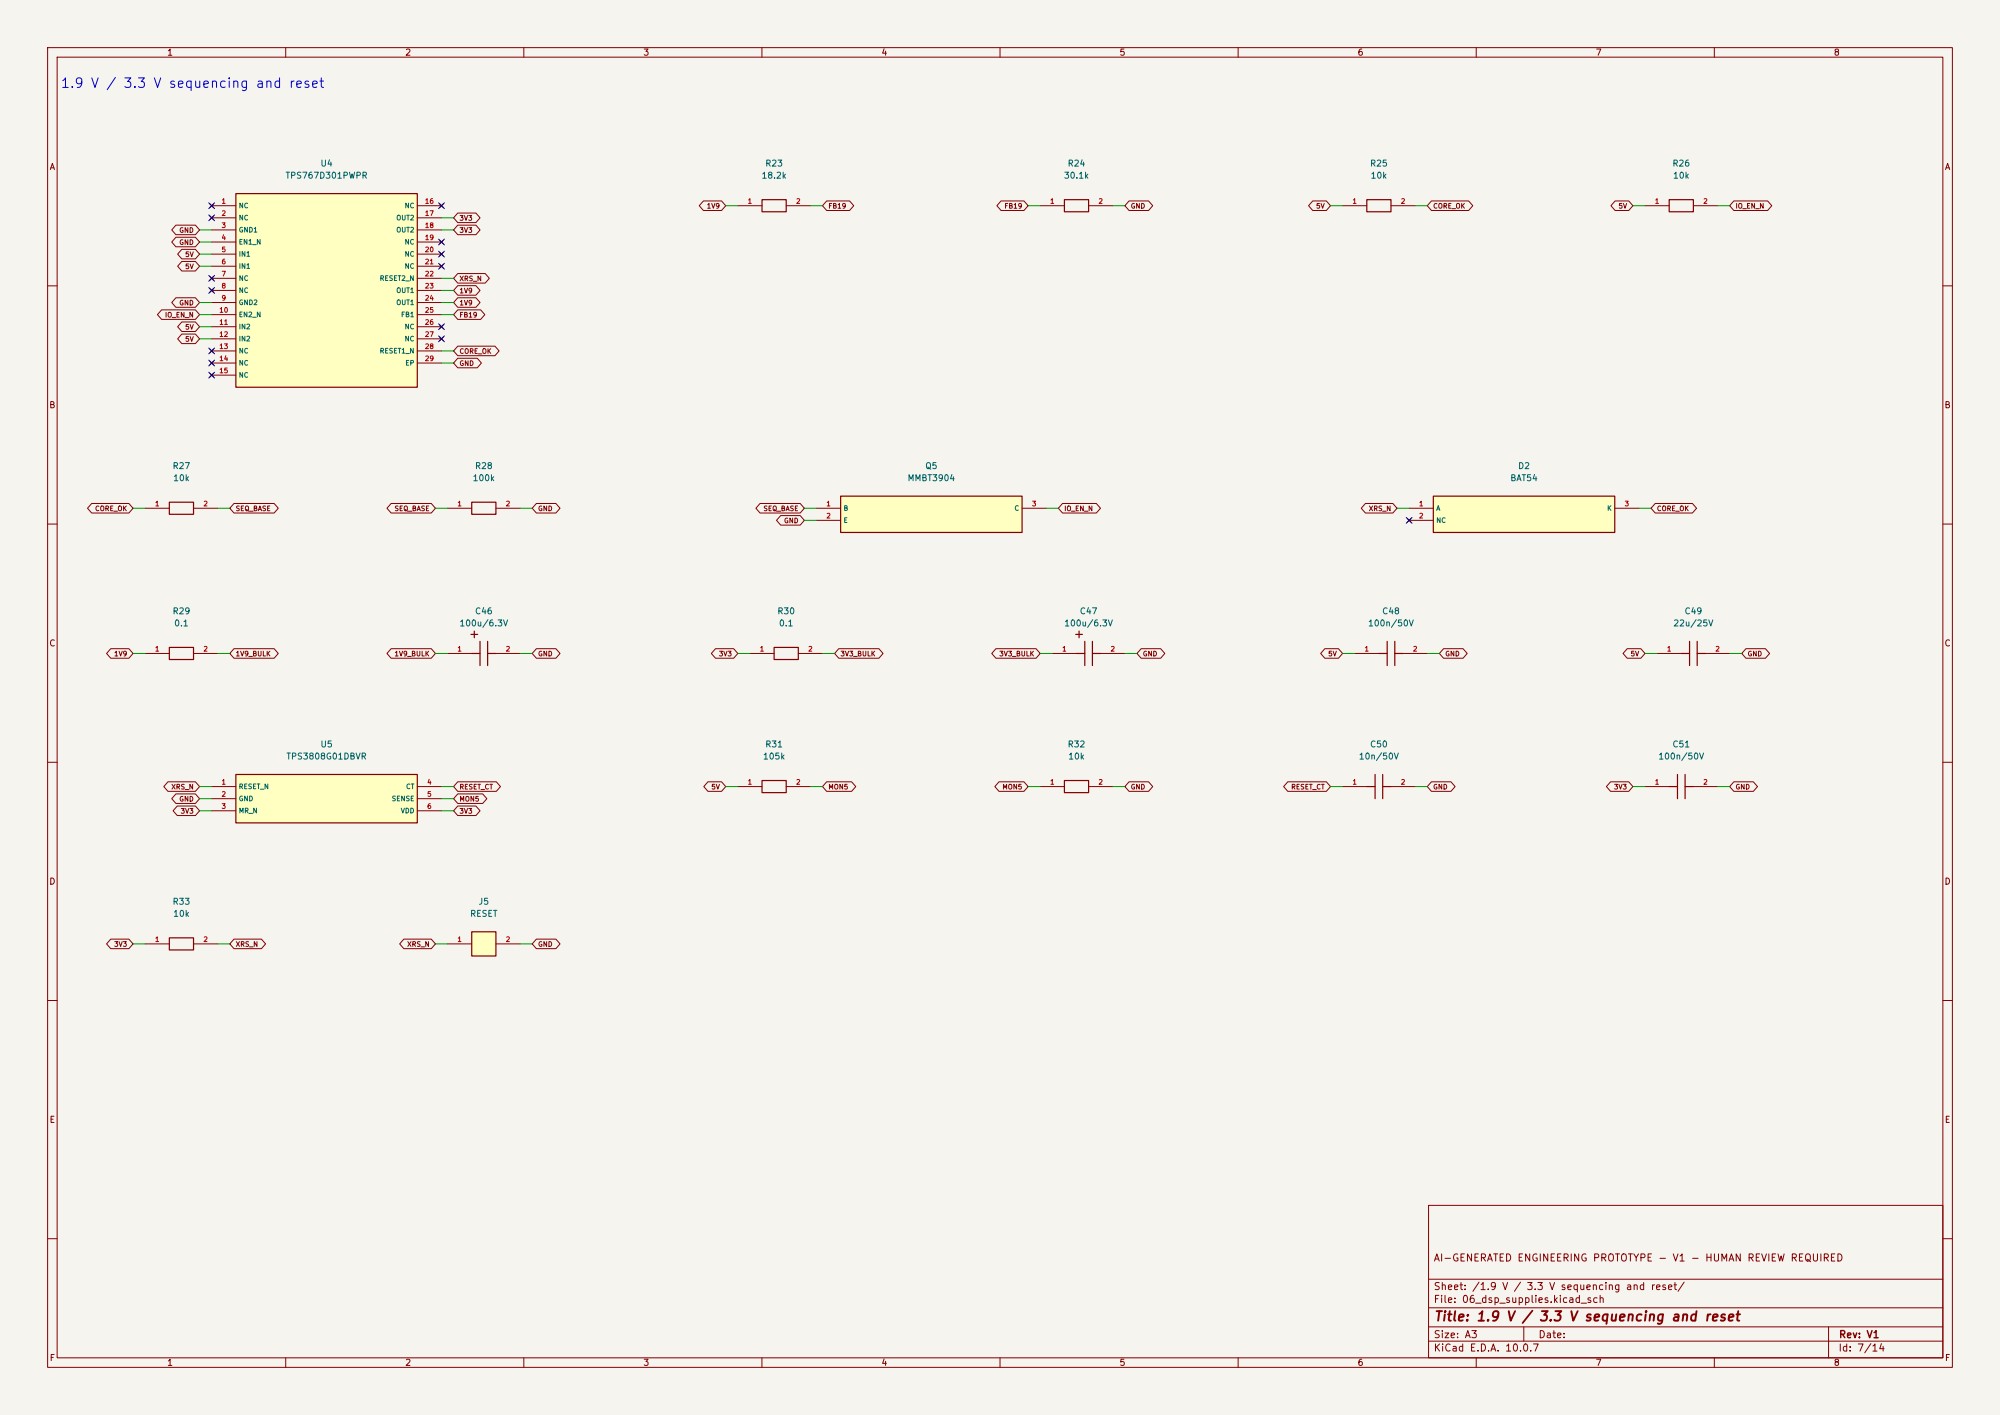
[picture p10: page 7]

AI-GENERATED ENGINEERING PROTOTYPE - V1 - HUMAN REVIEW REQUIRED

Sheet: /1.9 V / 3.3 V sequencing and reset/
File: 06_dsp_supplies.kicad_sch
Title: 1.9 V / 3.3 V sequencing and reset

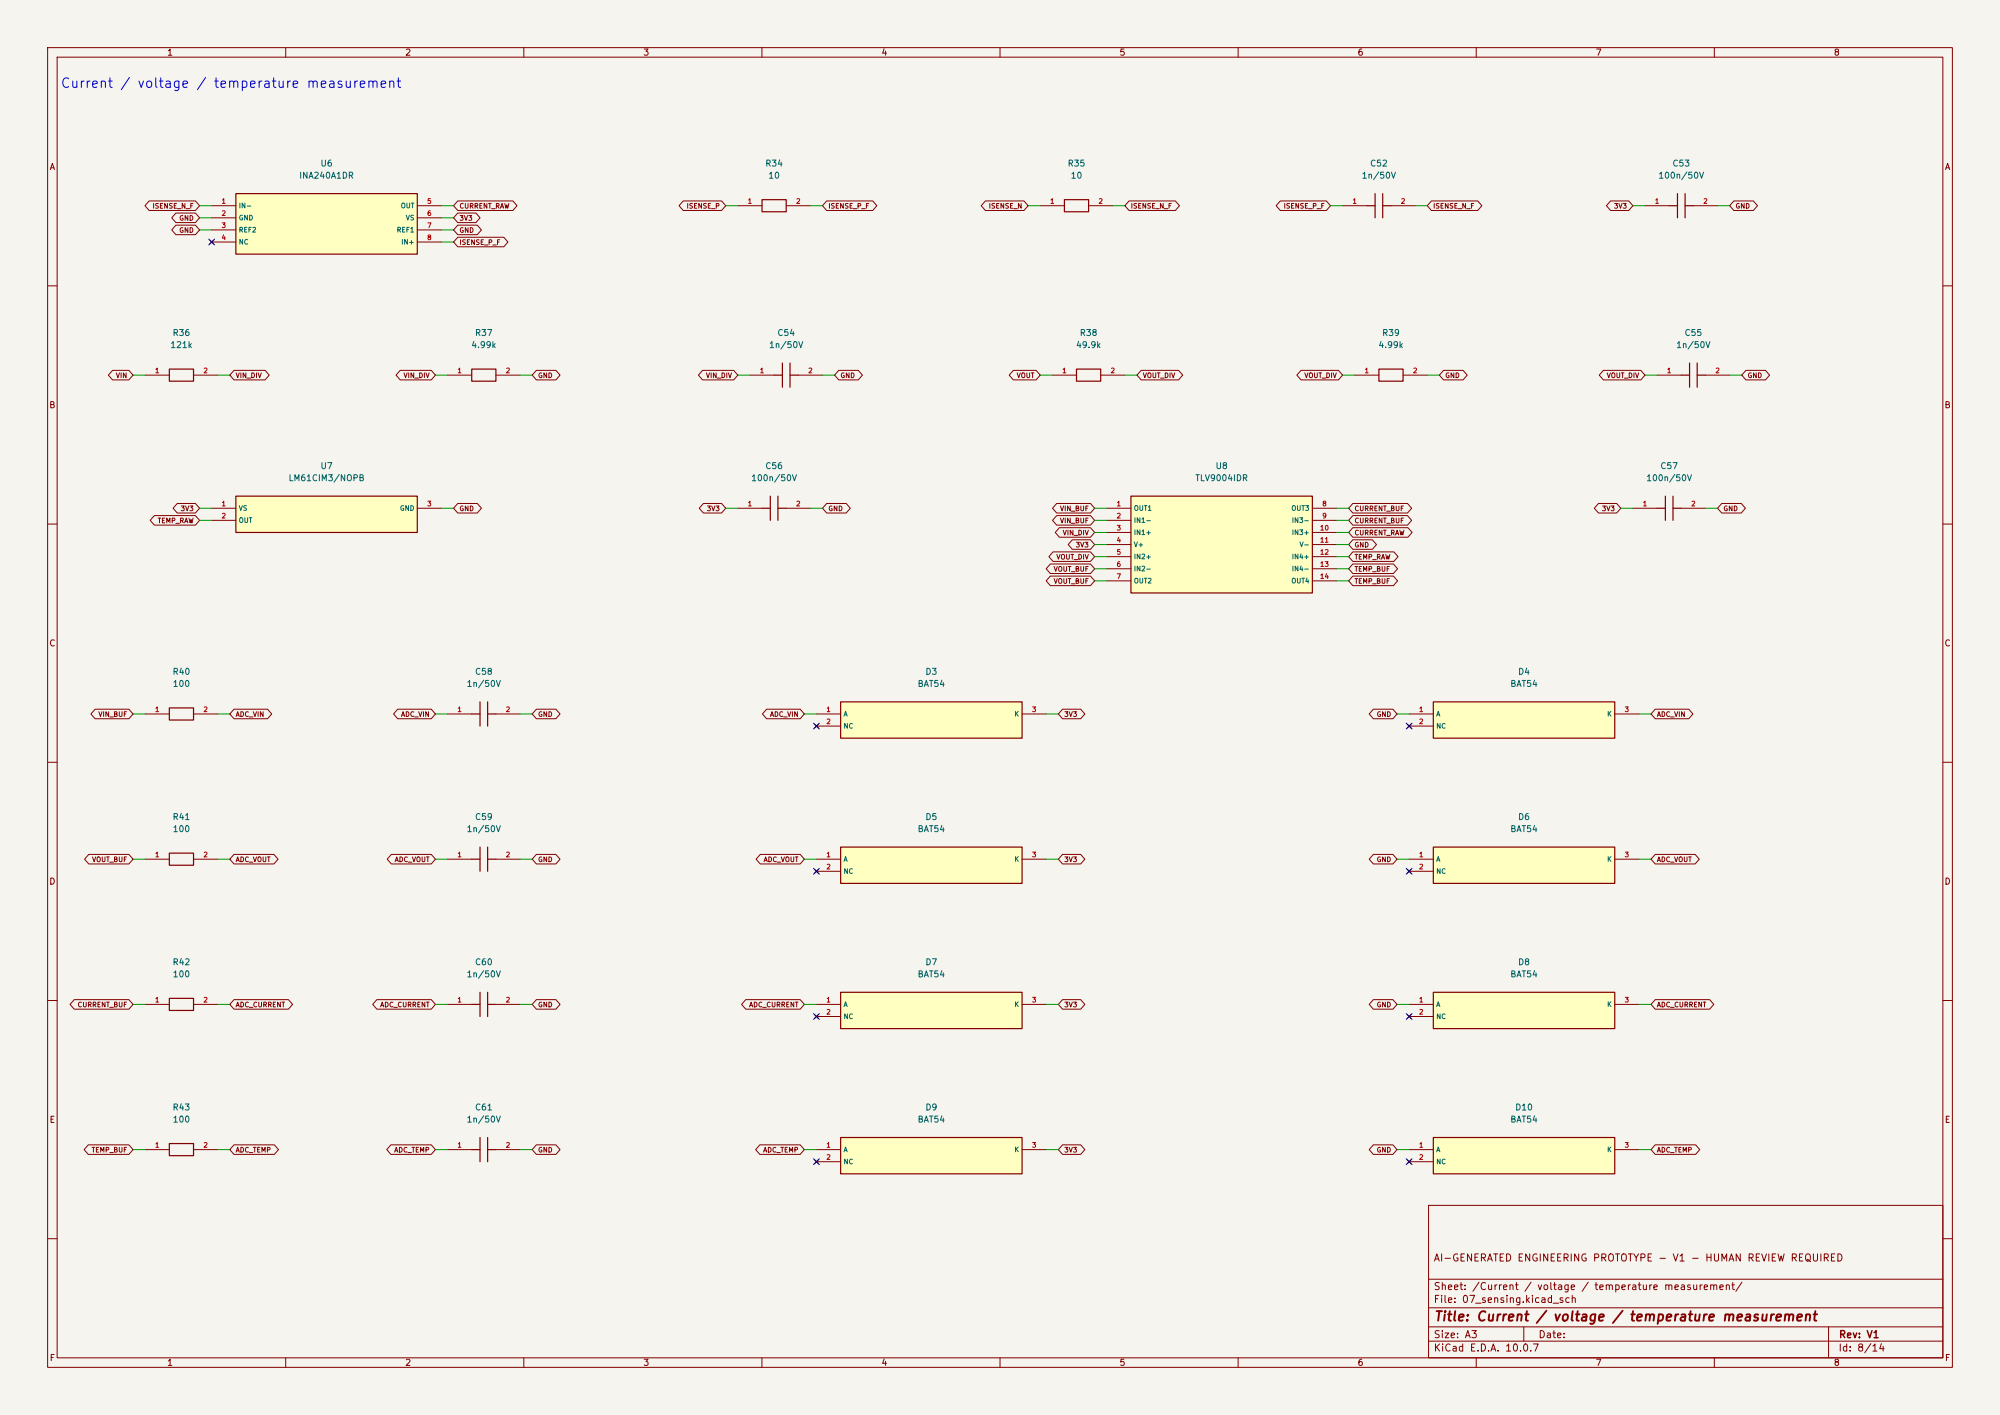
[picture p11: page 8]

TEMP_RAW Current / voltage / temperature measurement
VIN_DIV GND

AI-GENERATED ENGINEERING PROTOTYPE - V1 - HUMAN REVIEW REQUIRED

Sheet: /Current / voltage / temperature measurement/
File: 07_sensing.kicad_sch
Title: Current / voltage / temperature measurement

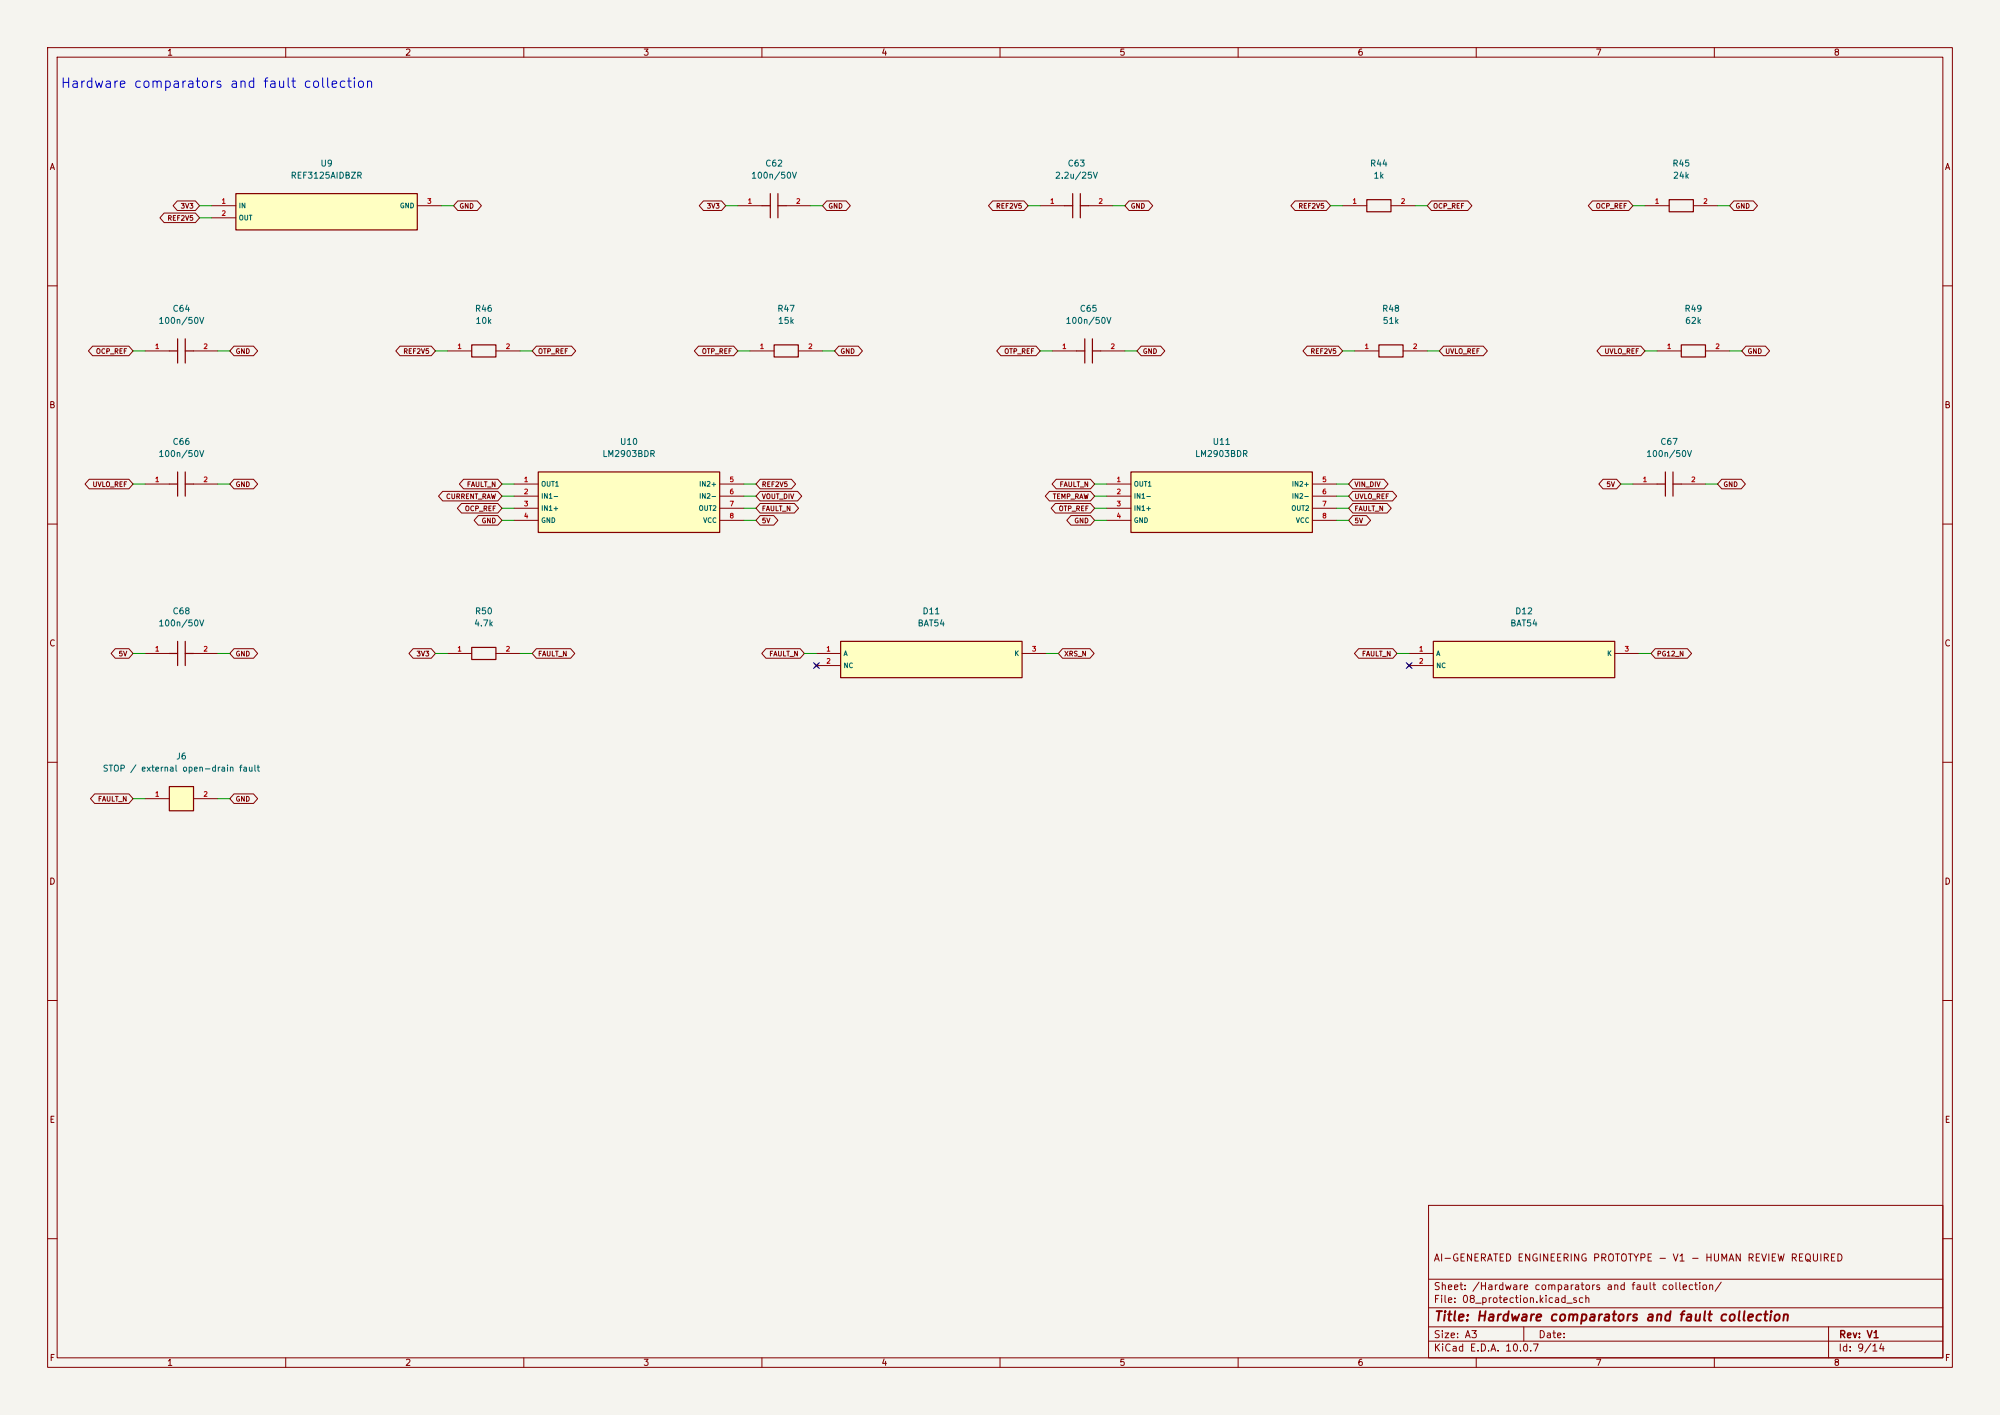
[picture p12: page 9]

CURRENT_RAW Hardware comparators and fault collection

STOP / external open-drain fault

AI-GENERATED ENGINEERING PROTOTYPE - V1 - HUMAN REVIEW REQUIRED

Sheet: /Hardware comparators and fault collection/
File: 08_protection.kicad_sch
Title: Hardware comparators and fault collection

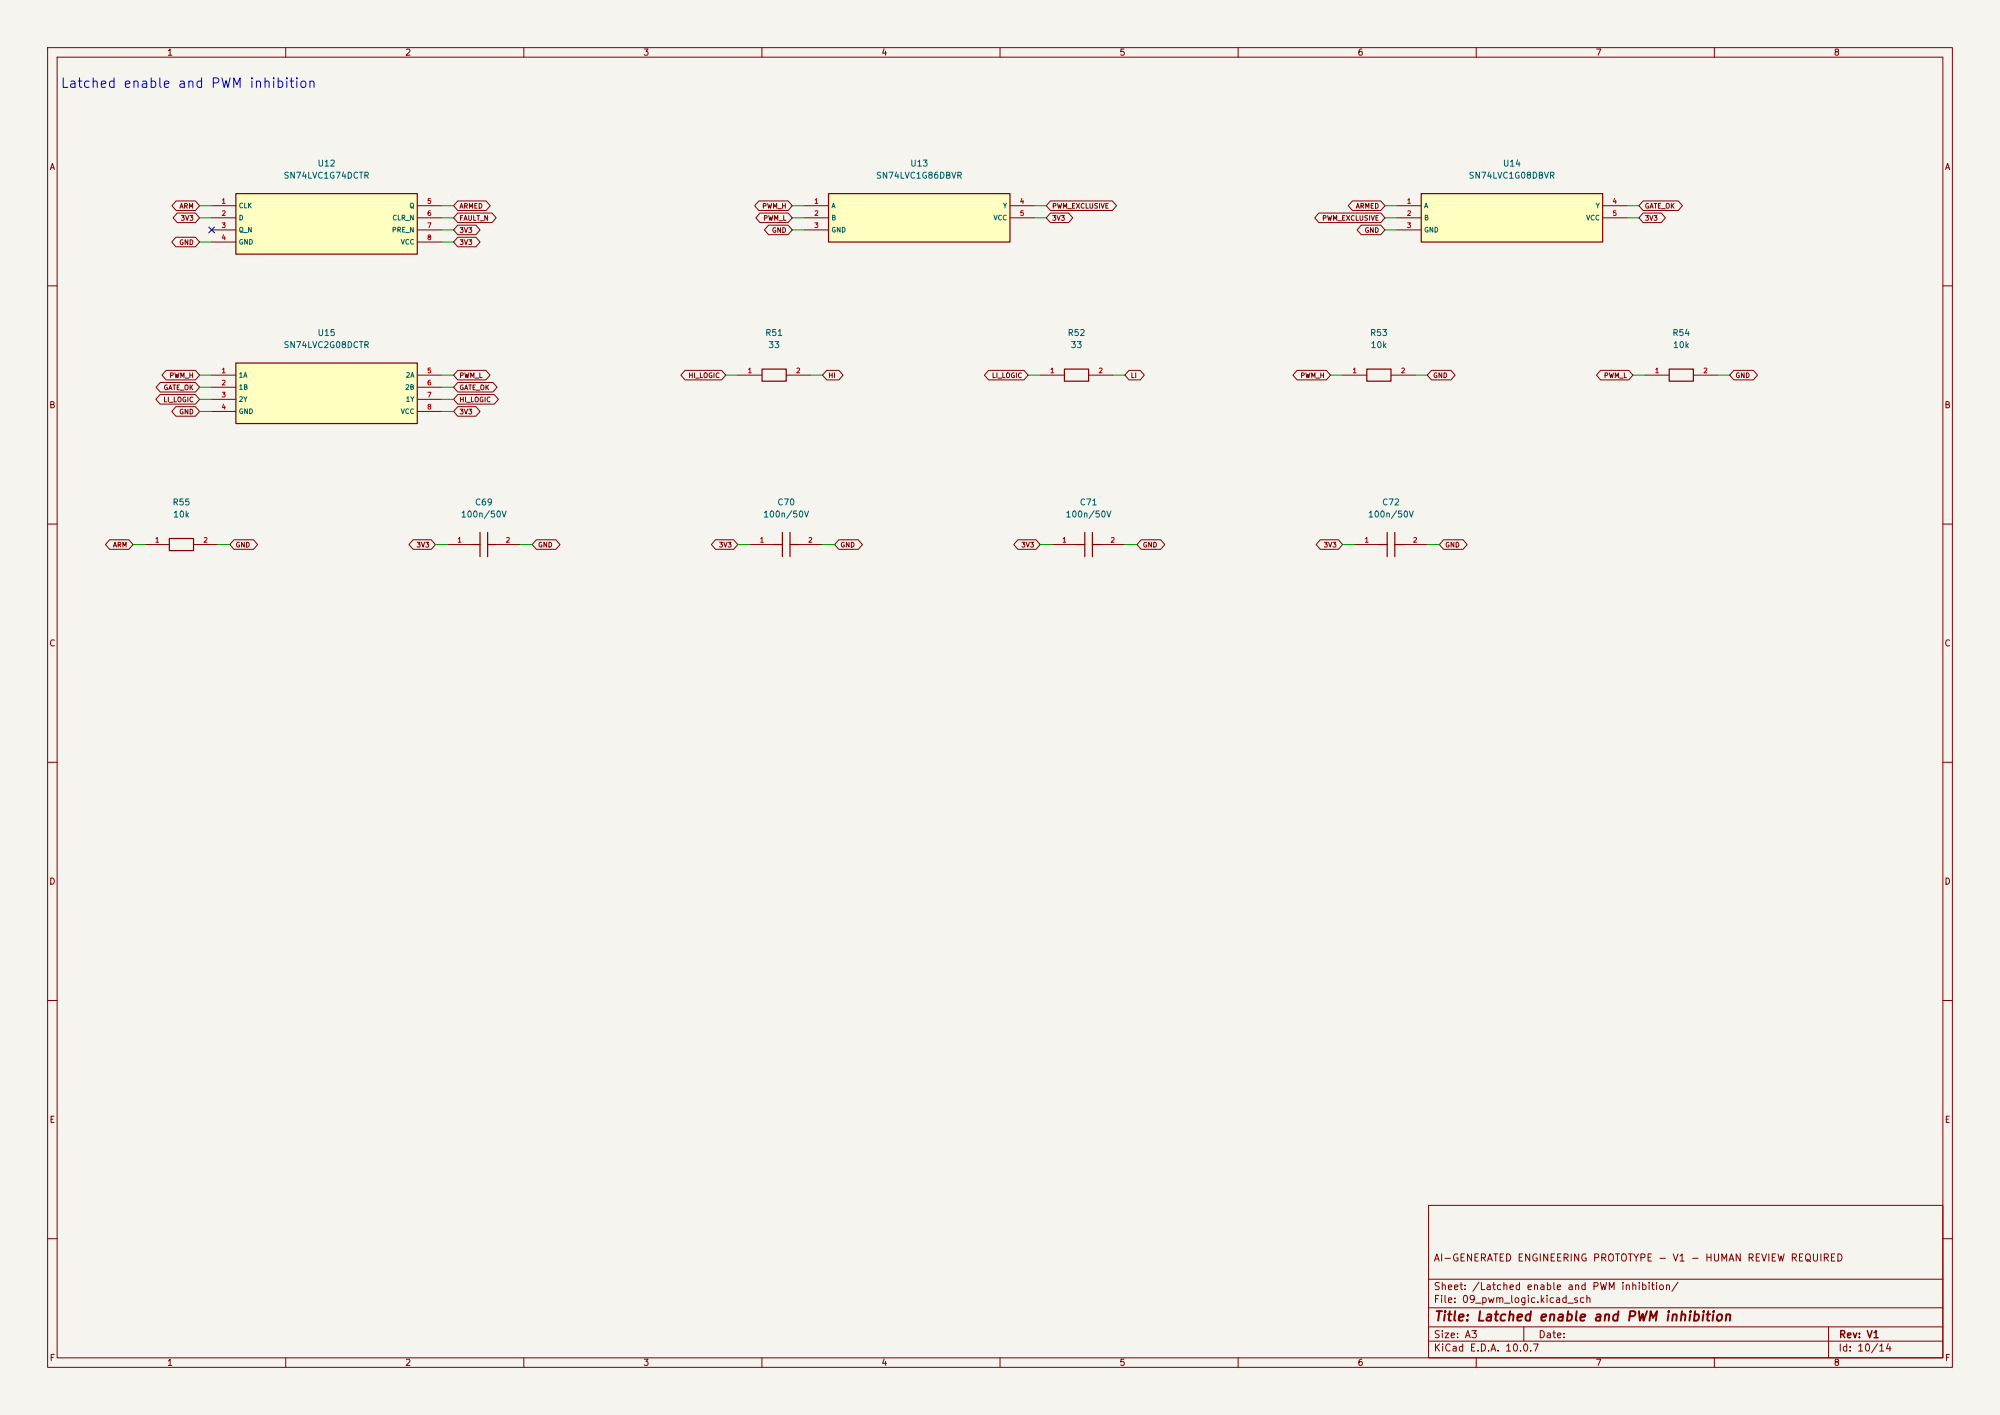
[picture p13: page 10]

AI-GENERATED ENGINEERING PROTOTYPE - V1 - HUMAN REVIEW REQUIRED

Sheet: /Latched enable and PWM inhibition/
File: 09_pwm_logic.kicad_sch
Title: Latched enable and PWM inhibition

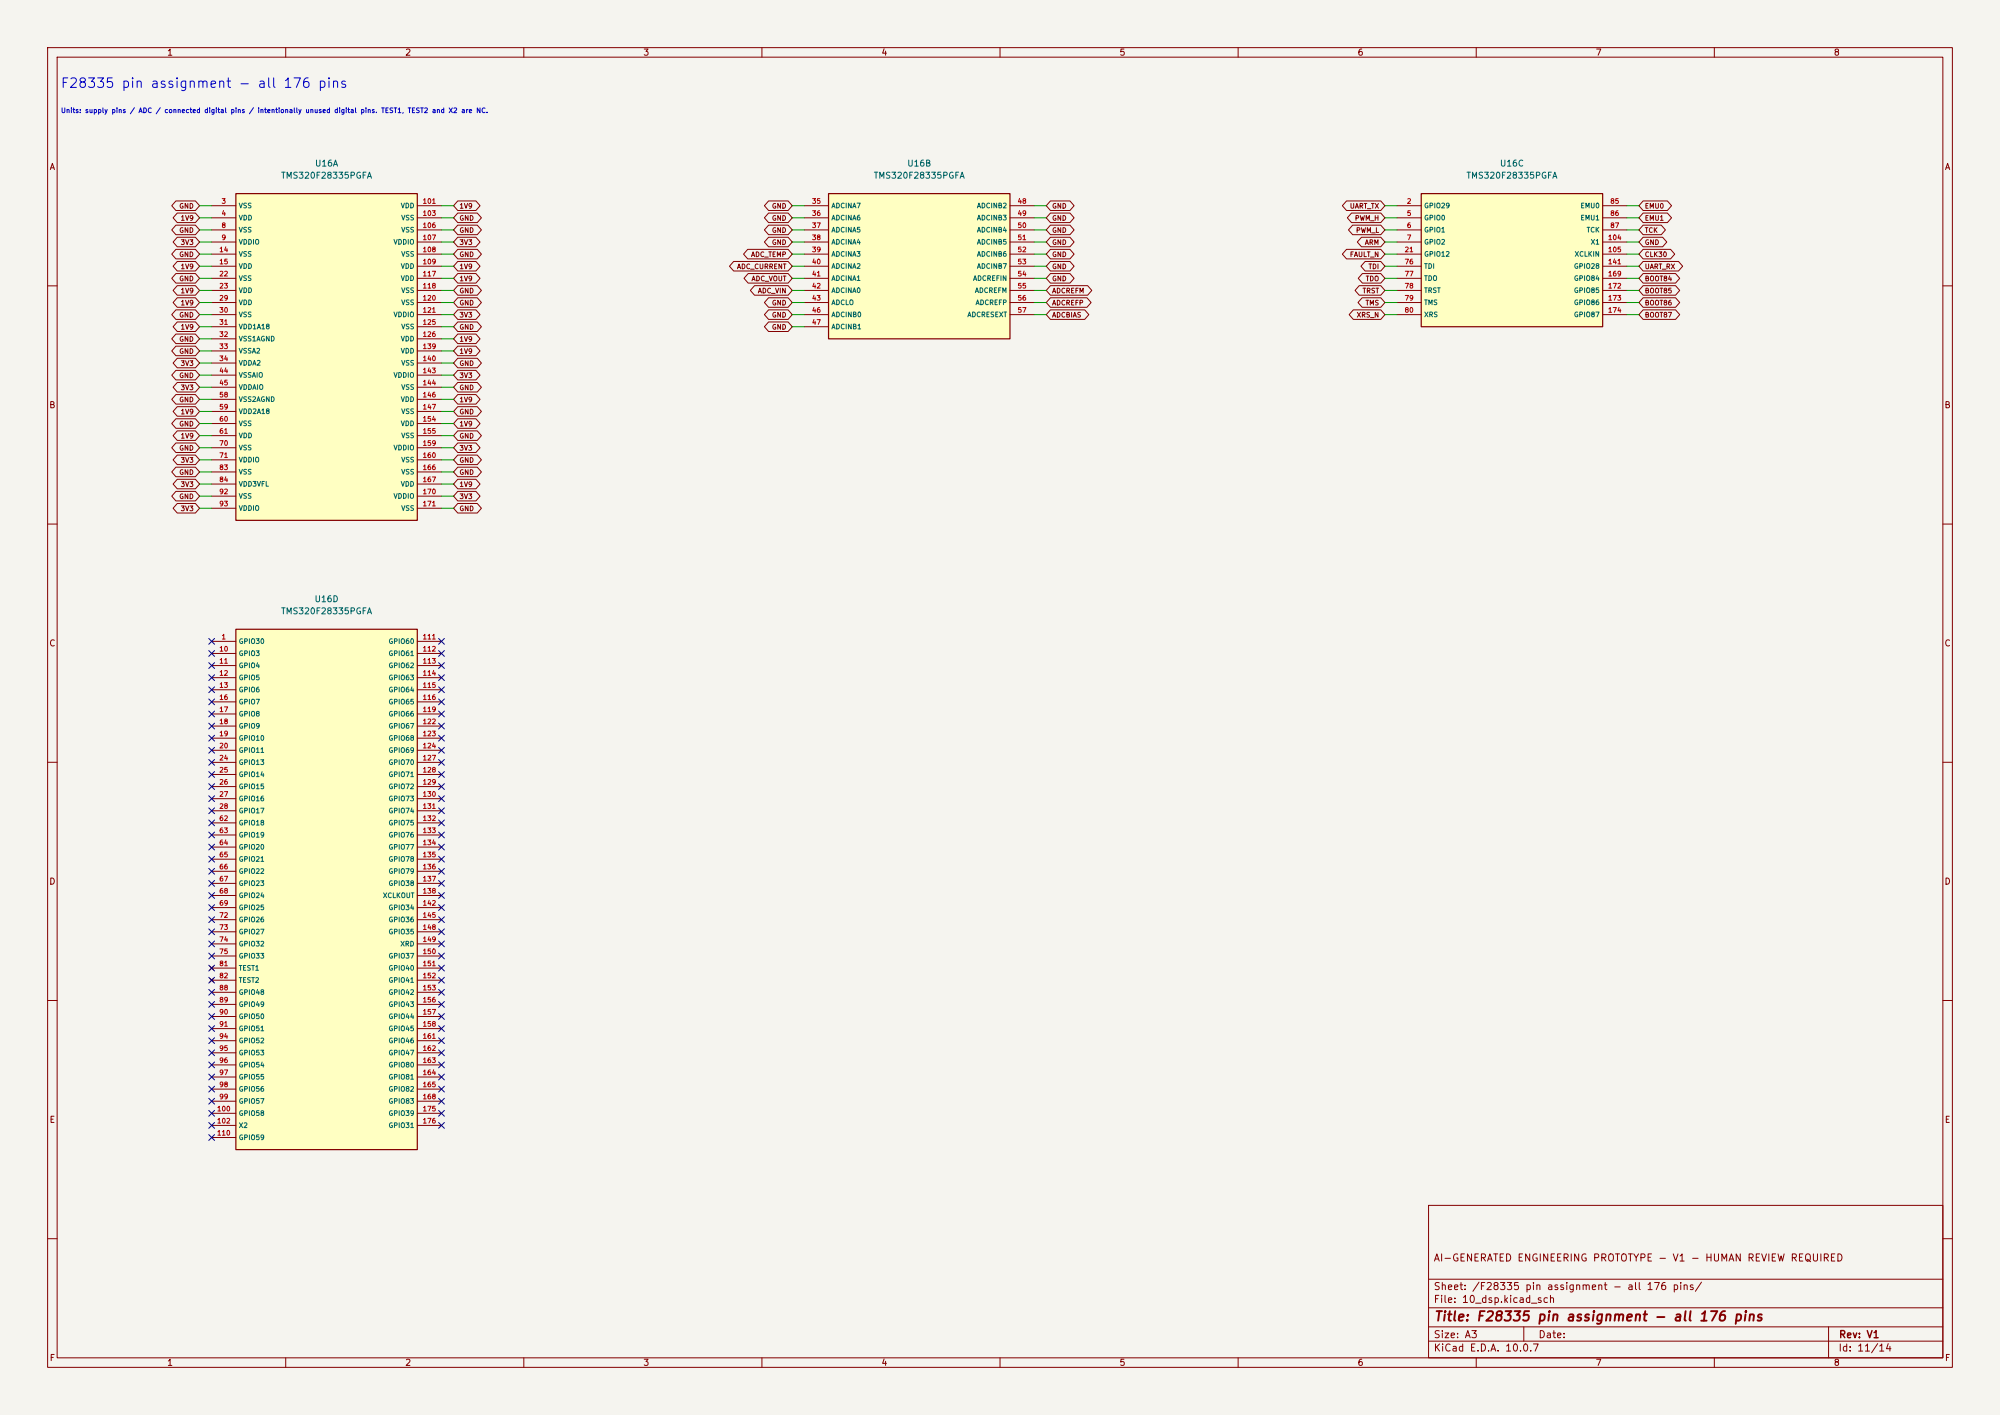
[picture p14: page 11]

3V3 GND F28335 pin assignment - all 176 pins

Units: supply pins / ADC / connected digital pins / intentionally unused digital pins. TEST1, TEST2 and X2 are NC.

AI-GENERATED ENGINEERING PROTOTYPE - V1 - HUMAN REVIEW REQUIRED

Sheet: /F28335 pin assignment - all 176 pins/
File: 10_dsp.kicad_sch
Title: F28335 pin assignment - all 176 pins

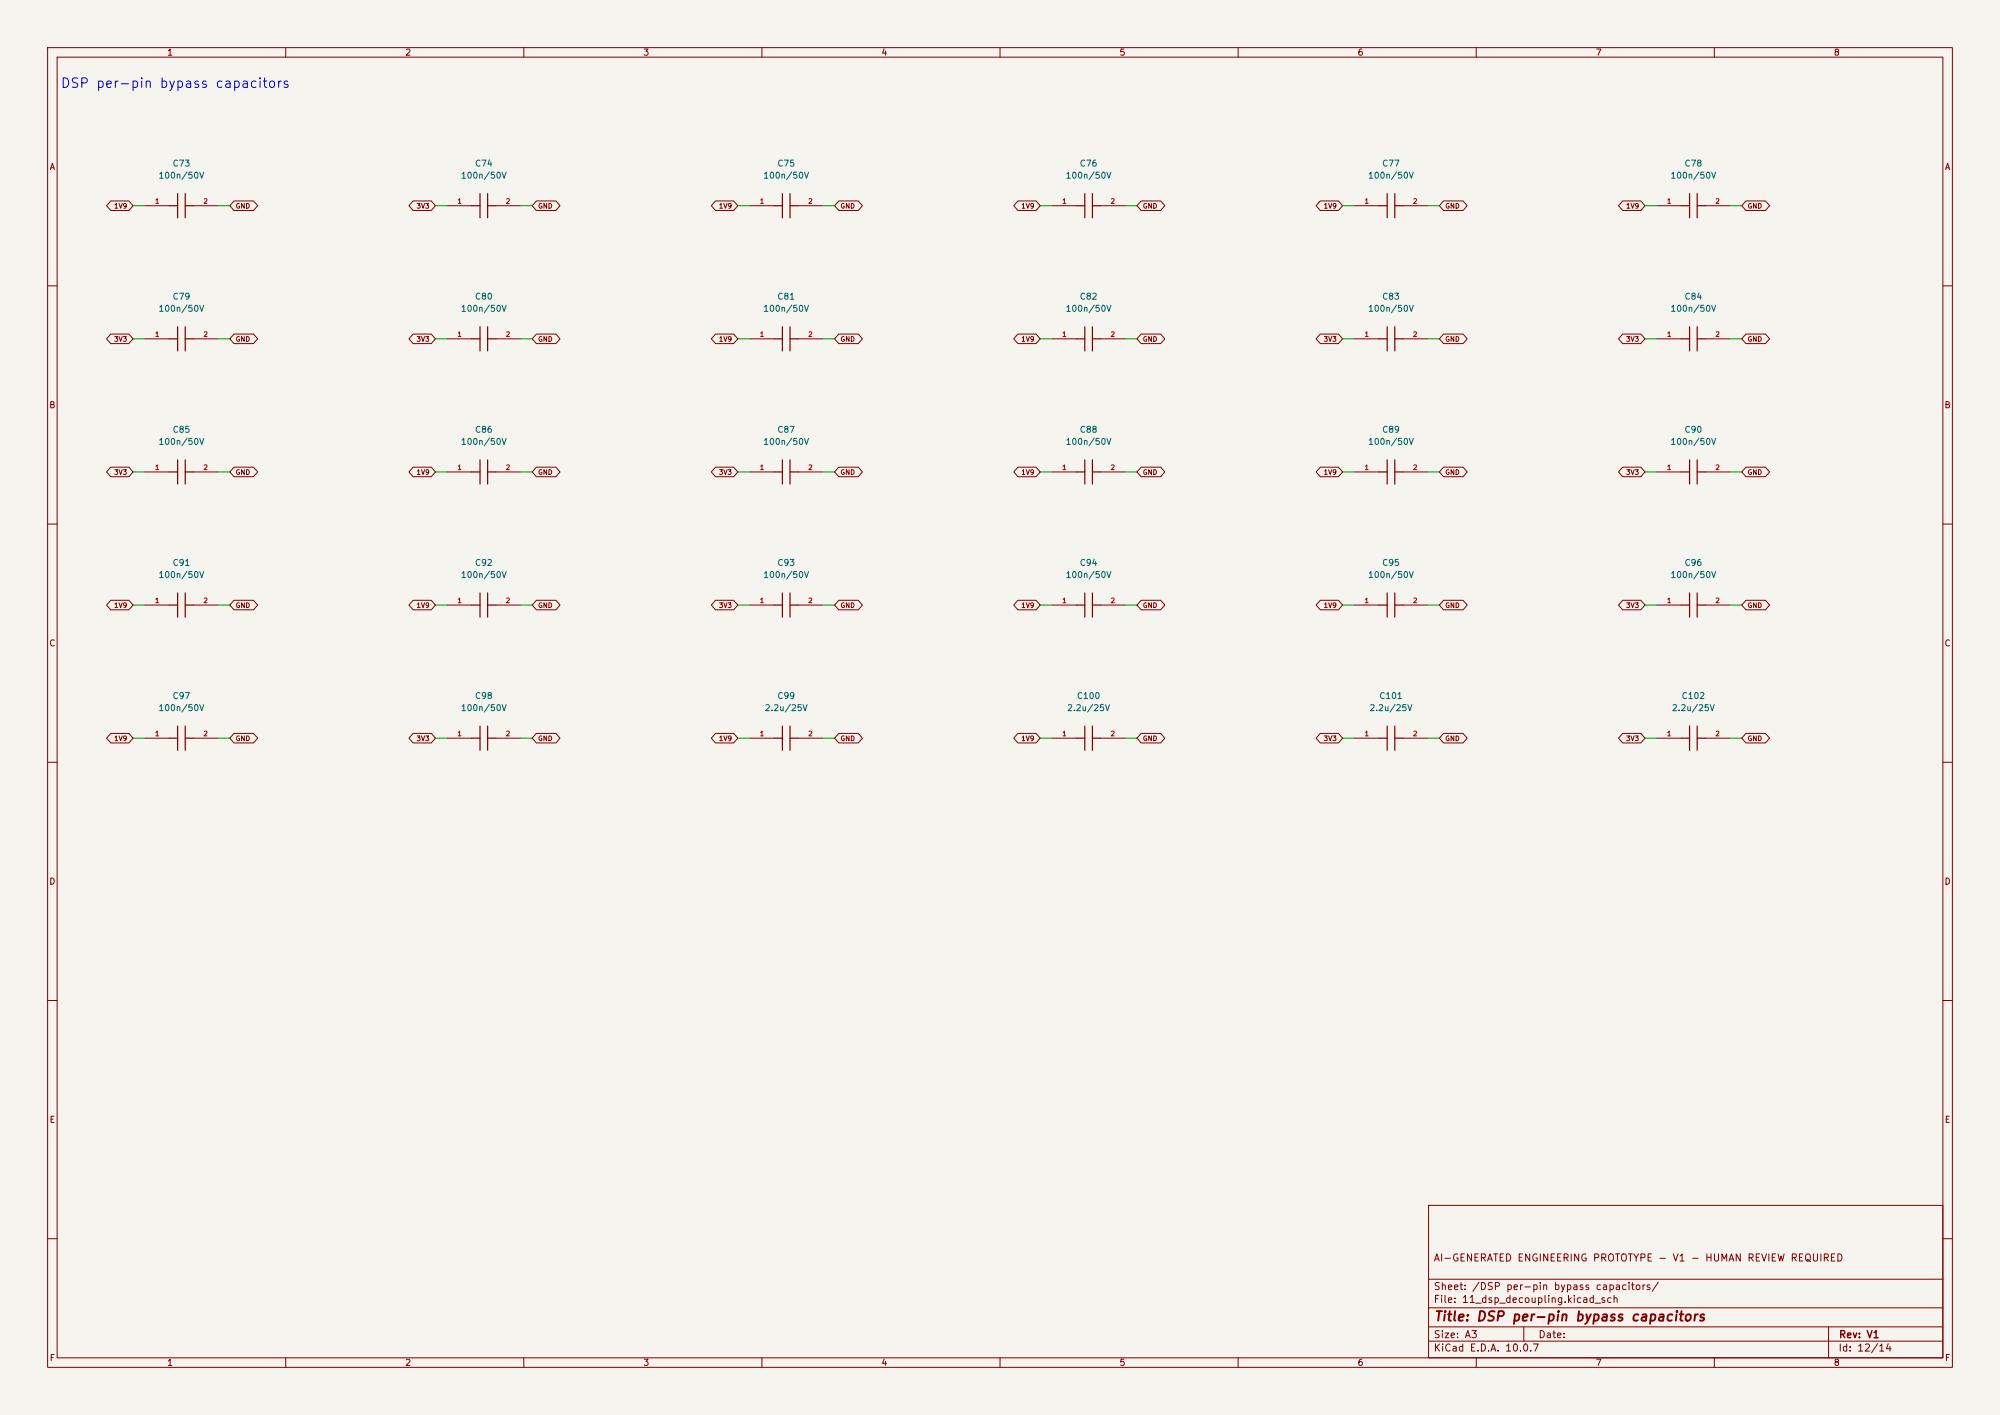
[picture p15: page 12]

3V3 DSP per-pin bypass capacitors

AI-GENERATED ENGINEERING PROTOTYPE - V1 - HUMAN REVIEW REQUIRED

Sheet: /DSP per-pin bypass capacitors/
File: 11_dsp_decoupling.kicad_sch
Title: DSP per-pin bypass capacitors

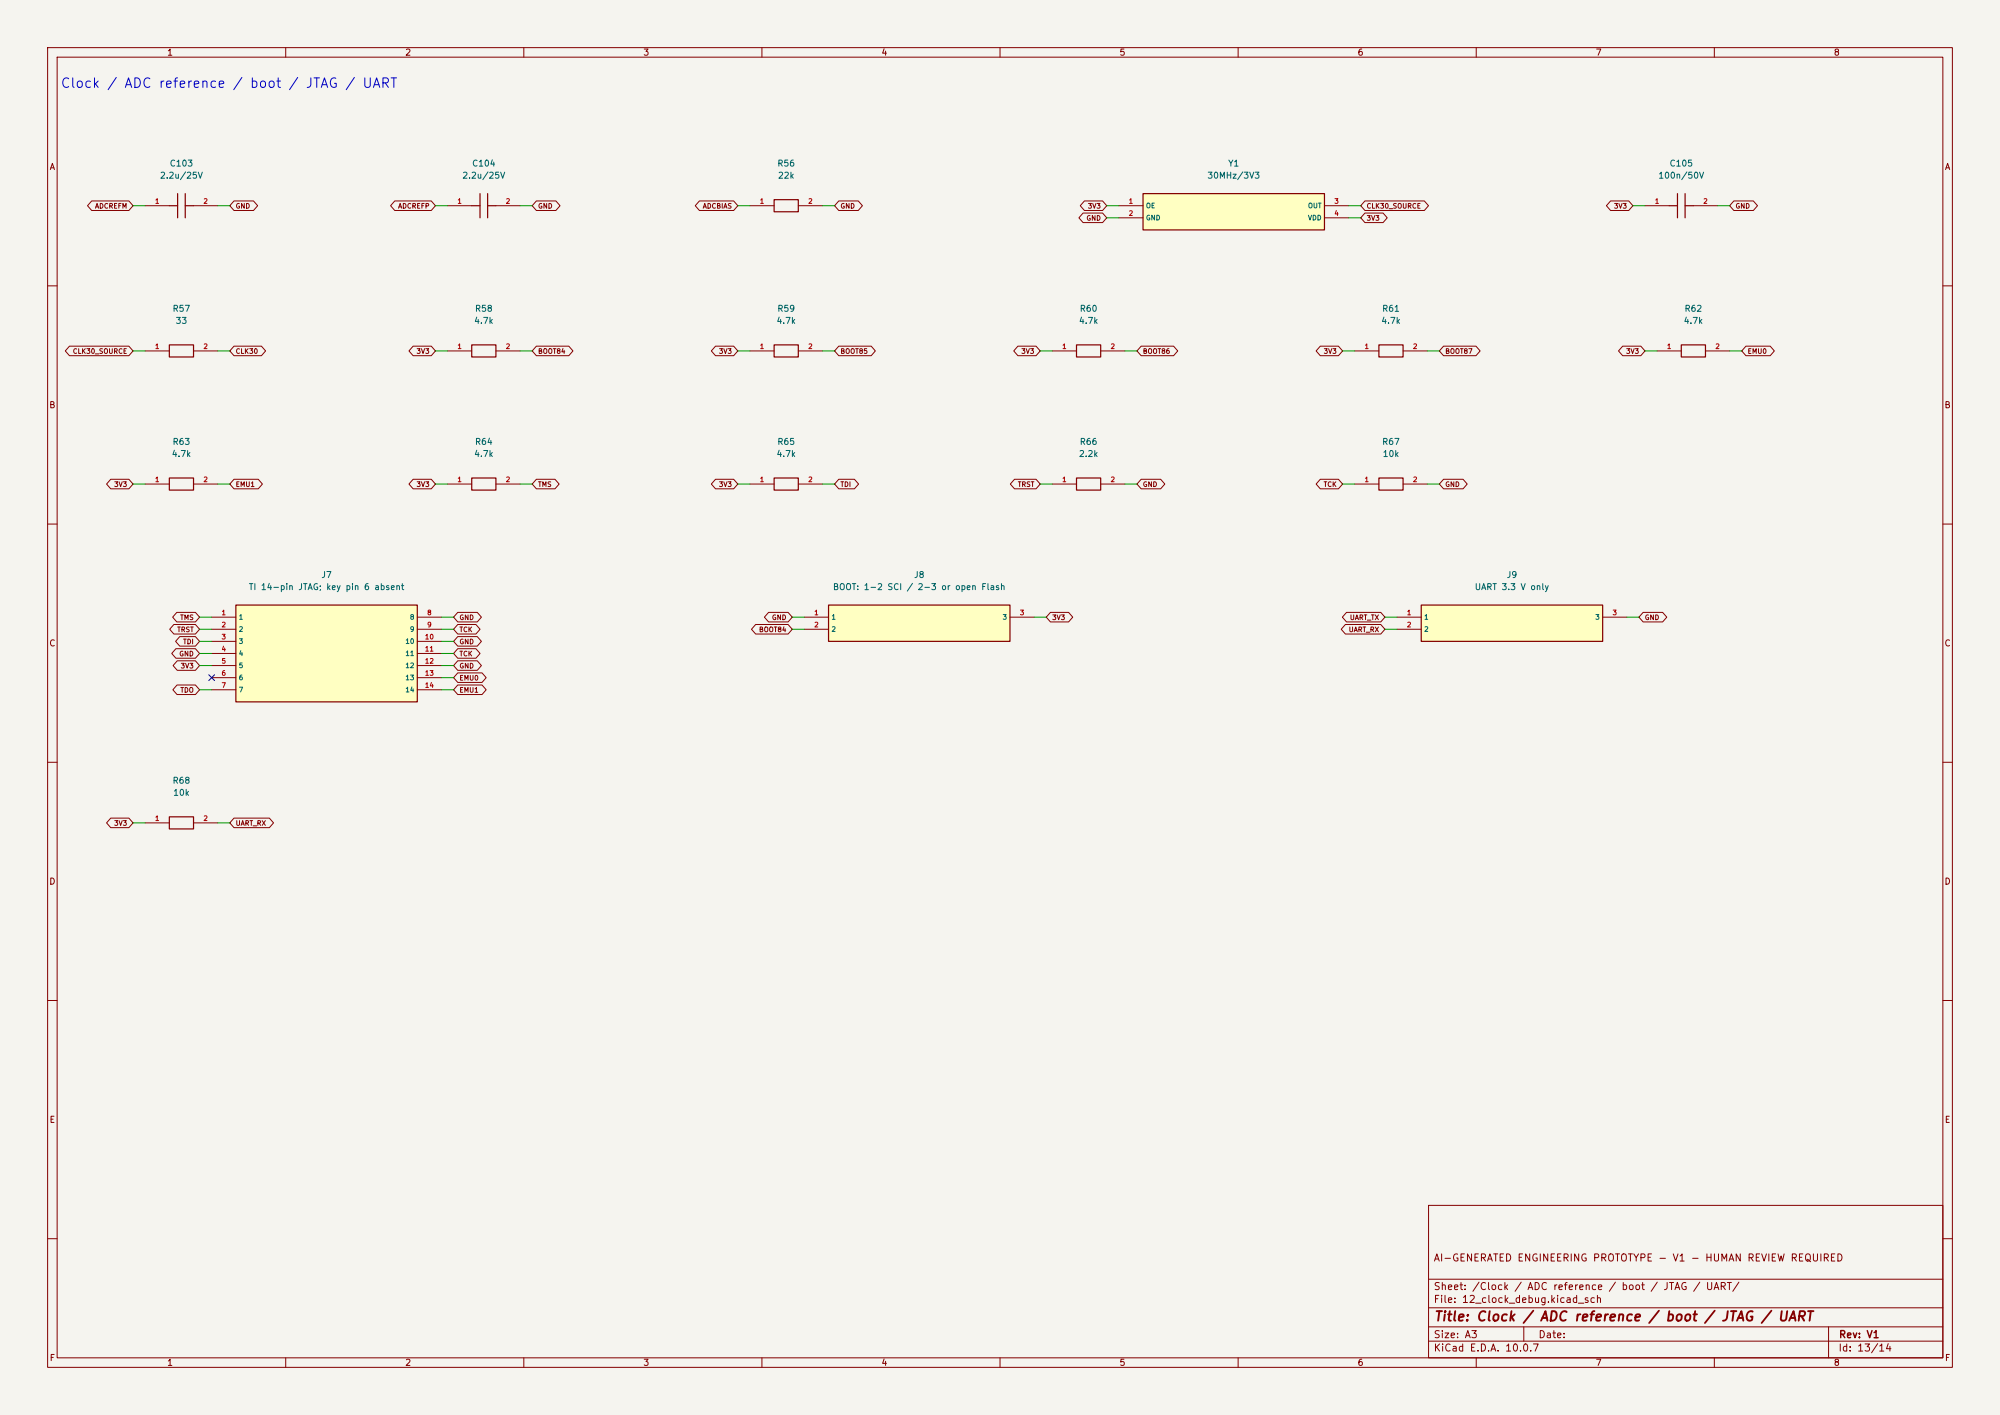
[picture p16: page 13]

BOOT87 Clock / ADC reference / boot / JTAG / UART

3 J8 BOOT: 1-2 SCI / 2-3 or open Flash

AI-GENERATED ENGINEERING PROTOTYPE - V1 - HUMAN REVIEW REQUIRED
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

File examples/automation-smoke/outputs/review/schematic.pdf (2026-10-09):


AUTOMATION TEST ONLY - NOT A POWER CONVERTER

Sheet: /
File: AIPE_Smoke.kicad_sch
Title: AIPE automation smoke test - passive divider

Size: A4 | Rev: smoke
KiCad E.D.A. 10.0.7 | Id: 1/1

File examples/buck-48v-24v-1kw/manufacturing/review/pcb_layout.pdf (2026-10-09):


AI-GENERATED ENGINEERING PROTOTYPE - HUMAN REVIEW REQUIRED

Size: A3 | Rev: V1 | F Date:
KiCad E.D.A. 10.0.7 | Id: 1/8


AI-GENERATED ENGINEERING PROTOTYPE - HUMAN REVIEW REQUIRED


AI-GENERATED ENGINEERING PROTOTYPE - HUMAN REVIEW REQUIRED


AI-GENERATED ENGINEERING PROTOTYPE - HUMAN REVIEW REQUIRED


AI-GENERATED ENGINEERING PROTOTYPE - HUMAN REVIEW REQUIRED


AI-GENERATED ENGINEERING PROTOTYPE - HUMAN REVIEW REQUIRED


AI-GENERATED ENGINEERING PROTOTYPE - HUMAN REVIEW REQUIRED


AI-GENERATED ENGINEERING PROTOTYPE - HUMAN REVIEW REQUIRED





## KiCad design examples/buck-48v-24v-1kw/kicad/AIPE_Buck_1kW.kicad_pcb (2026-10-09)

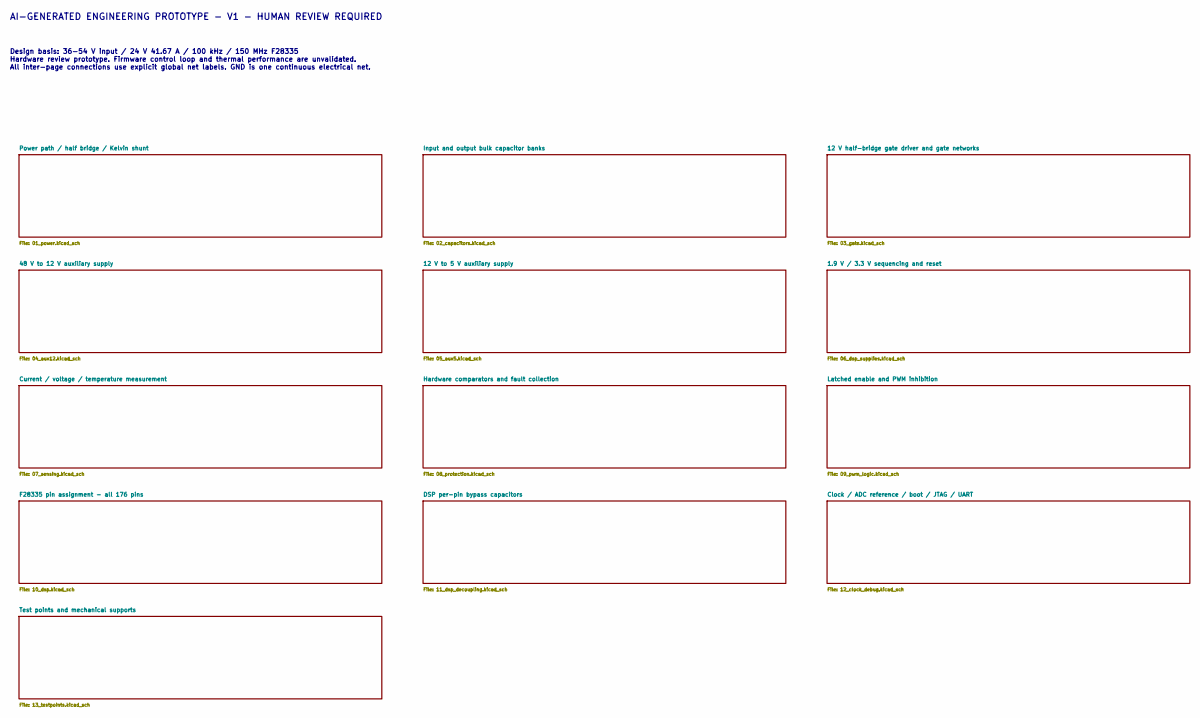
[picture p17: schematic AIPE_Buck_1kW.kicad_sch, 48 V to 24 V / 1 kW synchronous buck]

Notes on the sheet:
AI-GENERATED ENGINEERING PROTOTYPE - V1 - HUMAN REVIEW REQUIRED
Design basis: 36-54 V input / 24 V 41.67 A / 100 kHz / 150 MHz F28335 Hardware review prototype. Firmware control loop and thermal performance are unvalidated. All inter-page connections use explicit global net labels. GND is one continuous electrical net.

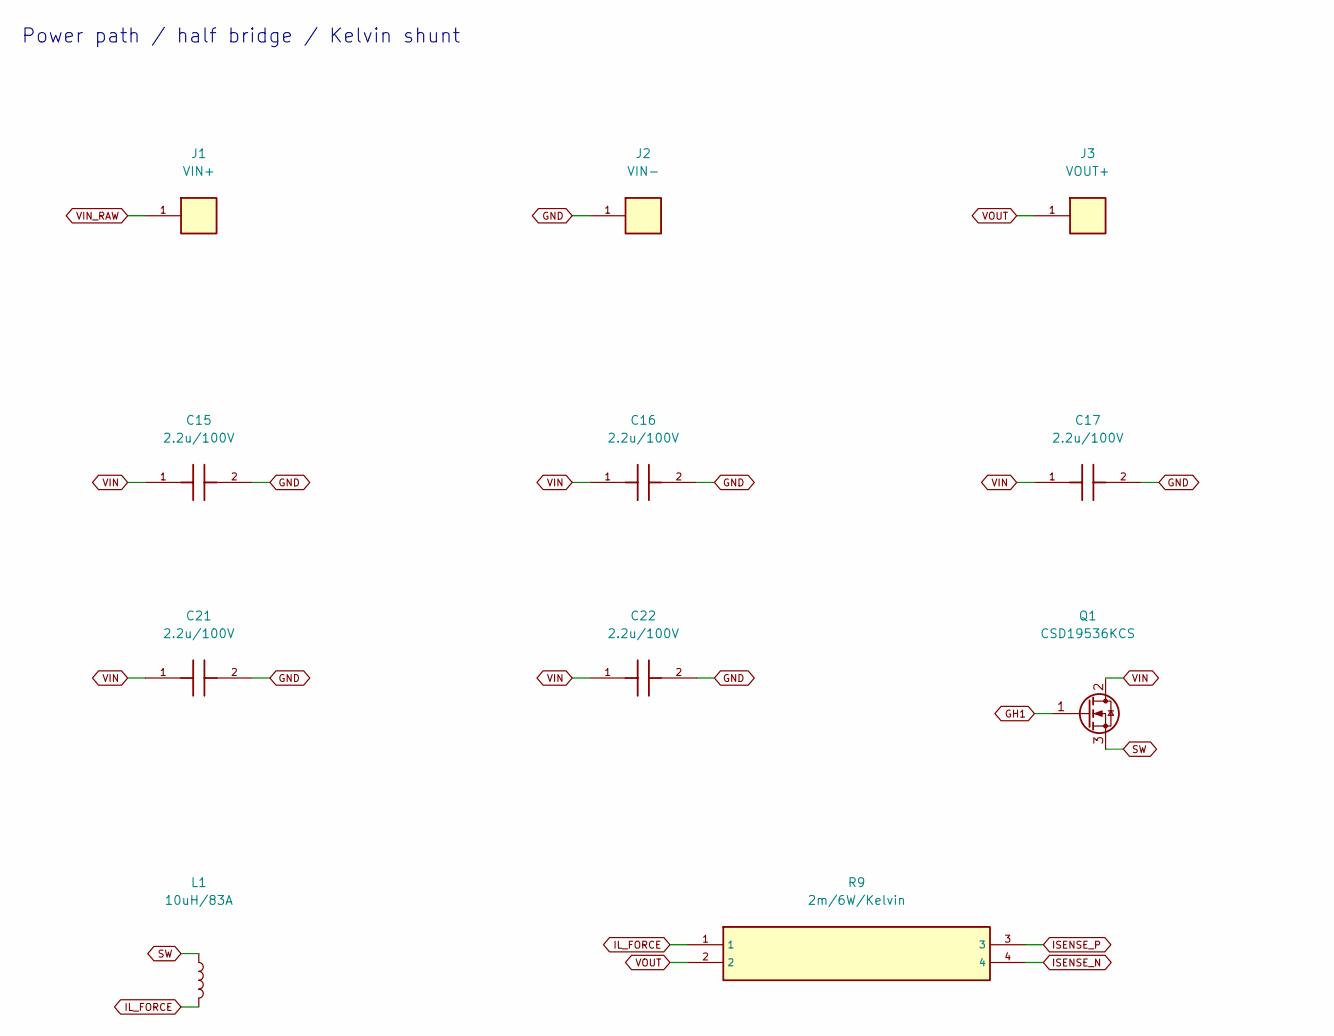
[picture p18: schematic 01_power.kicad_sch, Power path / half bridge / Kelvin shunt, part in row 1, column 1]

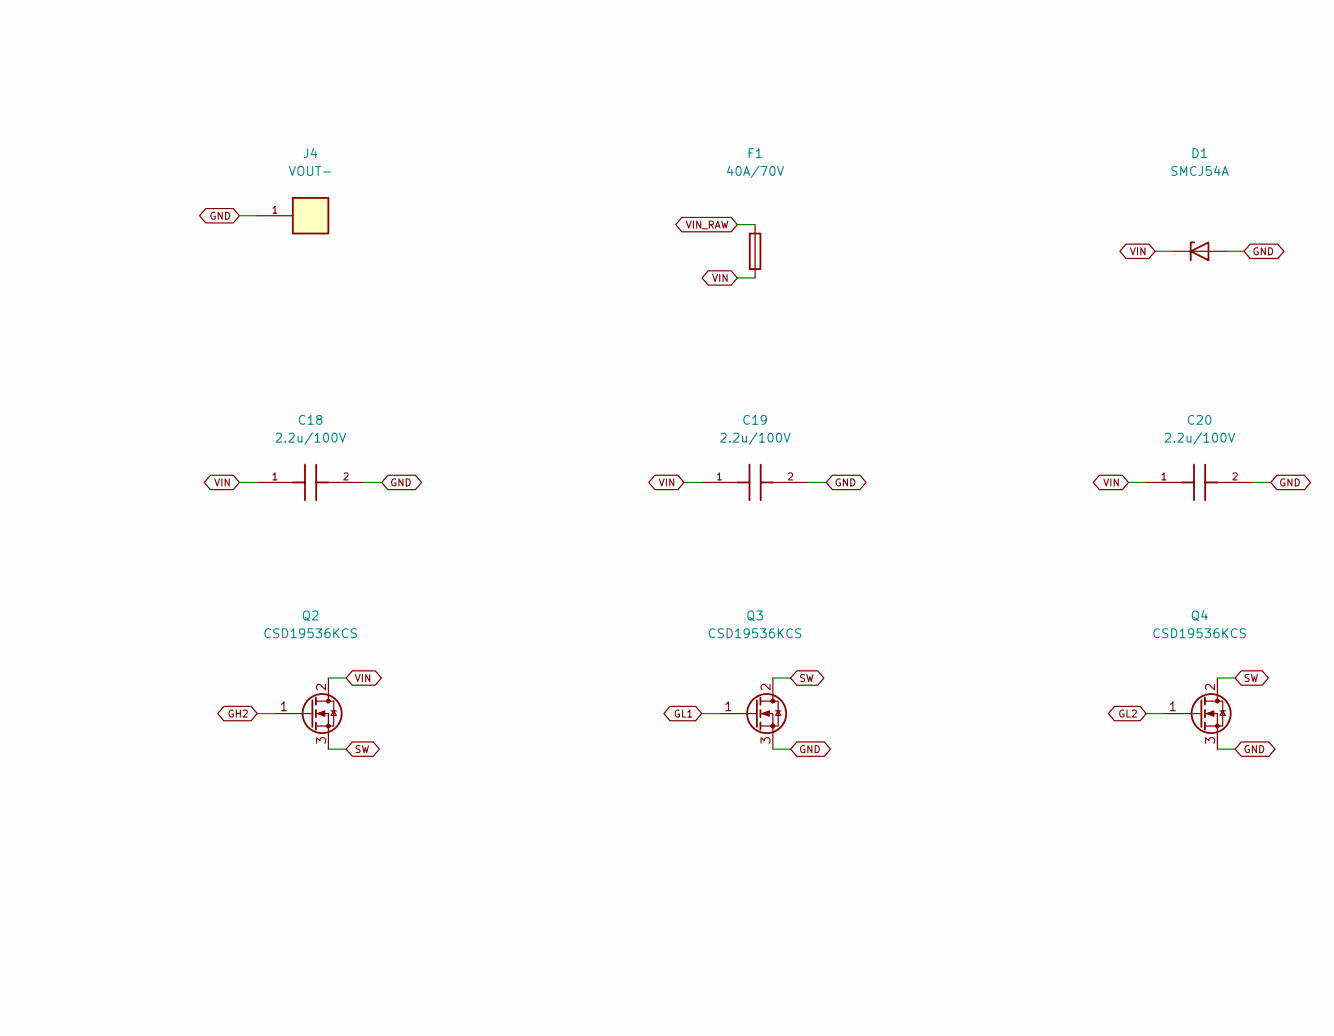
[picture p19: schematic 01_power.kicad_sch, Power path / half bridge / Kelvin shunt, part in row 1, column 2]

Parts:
C15, C16, C17, C18, C19, C20, C21, C22: 2.2u/100V; C_1210_3225Metric
D1: SMCJ54A; D_SMC
F1: 40A/70V; MIDI_70V_M6_P30
J1: VIN+; Wuerth_REDCUBE-THR_WP-THRSH_74651195_THR
J2: VIN-; Wuerth_REDCUBE-THR_WP-THRSH_74651195_THR
J3: VOUT+; Wuerth_REDCUBE-THR_WP-THRSH_74651195_THR
J4: VOUT-; Wuerth_REDCUBE-THR_WP-THRSH_74651195_THR
L1: 10uH/83A; IHXL2000VZ_10uH_Upright
Q1, Q2, Q3, Q4: CSD19536KCS; TO-220-3_Vertical
R9: 2m/6W/Kelvin; CSS4J_4026_Kelvin

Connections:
GH1: Q1.1 (G); also elsewhere on the board
GH2: Q2.1 (G); also elsewhere on the board
GL1: Q3.1 (G); also elsewhere on the board
GL2: Q4.1 (G); also elsewhere on the board
GND: C15.2, C16.2, C17.2, C18.2, C19.2, C20.2, C21.2, C22.2, D1.2 (A), J2.1, J4.1, Q3.3 (S), Q4.3 (S); also elsewhere on the board
IL_FORCE: L1.2, R9.1
ISENSE_N: R9.4; also elsewhere on the board
ISENSE_P: R9.3; also elsewhere on the board
SW: L1.1, Q1.3 (S), Q2.3 (S), Q3.2 (D), Q4.2 (D); also elsewhere on the board
VIN: C15.1, C16.1, C17.1, C18.1, C19.1, C20.1, C21.1, C22.1, D1.1 (K), F1.2, Q1.2 (D), Q2.2 (D); also elsewhere on the board
VIN_RAW: F1.1, J1.1
VOUT: J3.1, R9.2; also elsewhere on the board

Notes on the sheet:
Power path / half bridge / Kelvin shunt

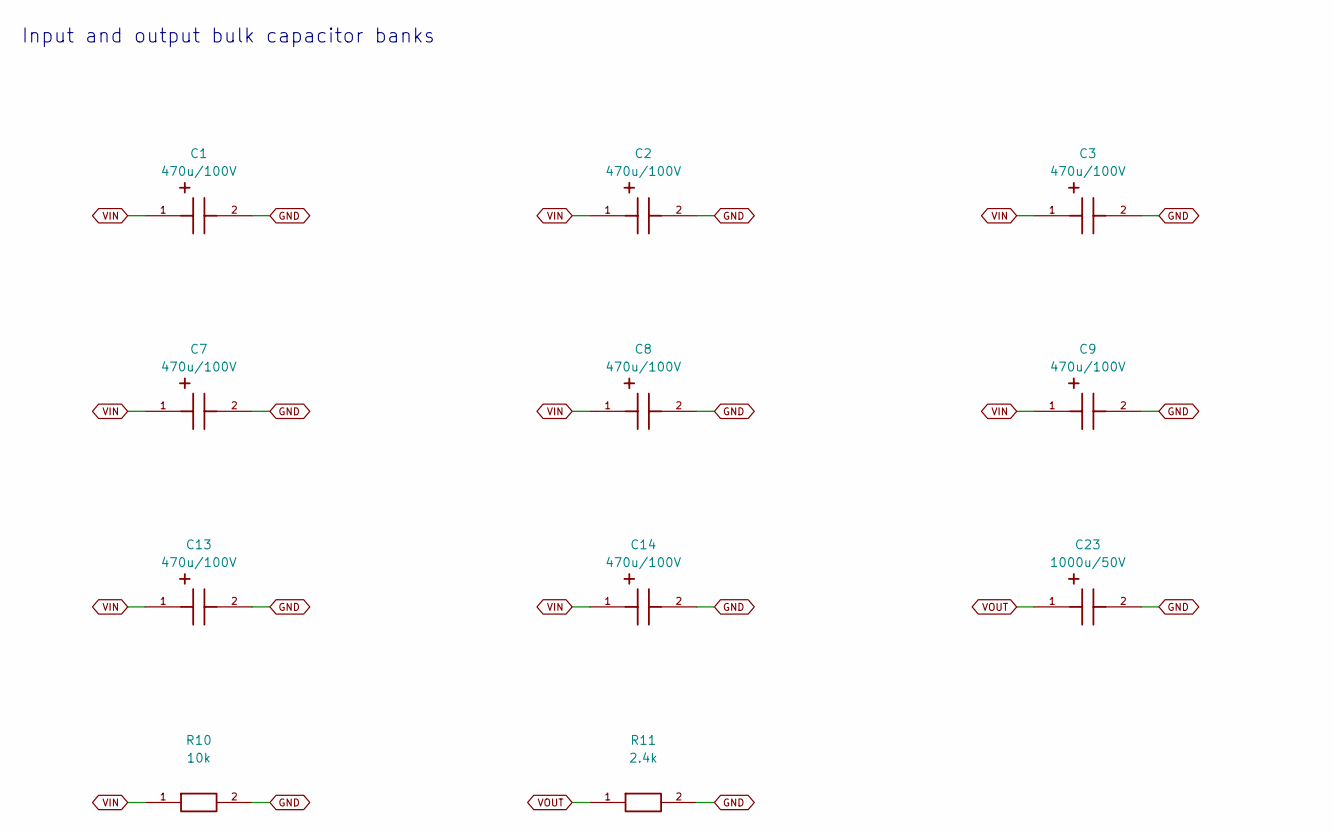
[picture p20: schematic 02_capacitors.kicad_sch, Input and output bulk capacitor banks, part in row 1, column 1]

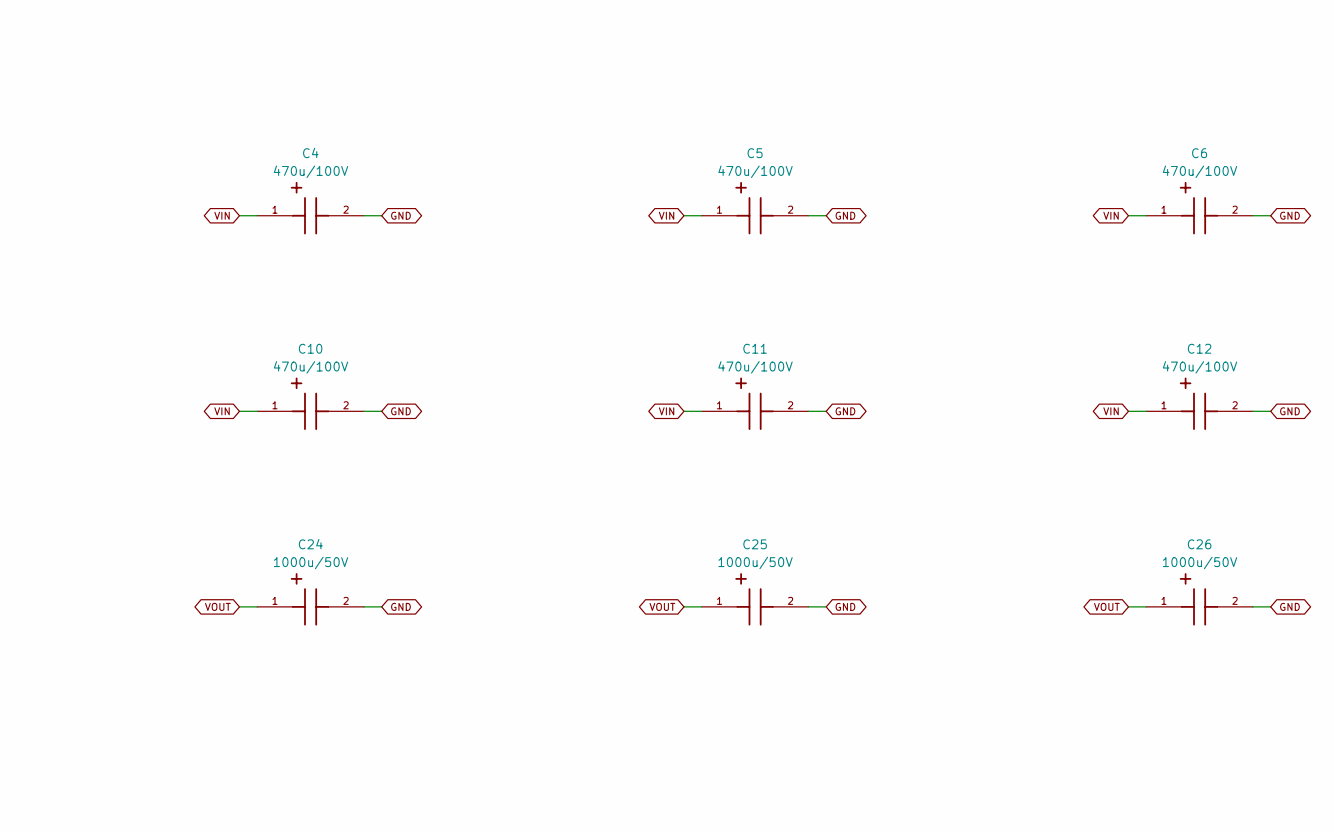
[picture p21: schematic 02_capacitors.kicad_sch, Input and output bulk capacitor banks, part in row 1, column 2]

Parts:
C1, C2, C3, C4, C5, C6, C7, C8, C9, C10, C11, C12, C13, C14: 470u/100V; CP_Radial_D18.0mm_P7.50mm
C23, C24, C25, C26: 1000u/50V; CP_Radial_D16.0mm_P7.50mm
R10: 10k; R_2512_6332Metric
R11: 2.4k; R_2512_6332Metric

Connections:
GND: C1.2, C2.2, C3.2, C4.2, C5.2, C6.2, C7.2, C8.2, C9.2, C10.2, C11.2, C12.2, C13.2, C14.2, C23.2, C24.2, C25.2, C26.2, R10.2, R11.2; also elsewhere on the board
VIN: C1.1, C2.1, C3.1, C4.1, C5.1, C6.1, C7.1, C8.1, C9.1, C10.1, C11.1, C12.1, C13.1, C14.1, R10.1; also elsewhere on the board
VOUT: C23.1, C24.1, C25.1, C26.1, R11.1; also elsewhere on the board

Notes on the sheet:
Input and output bulk capacitor banks

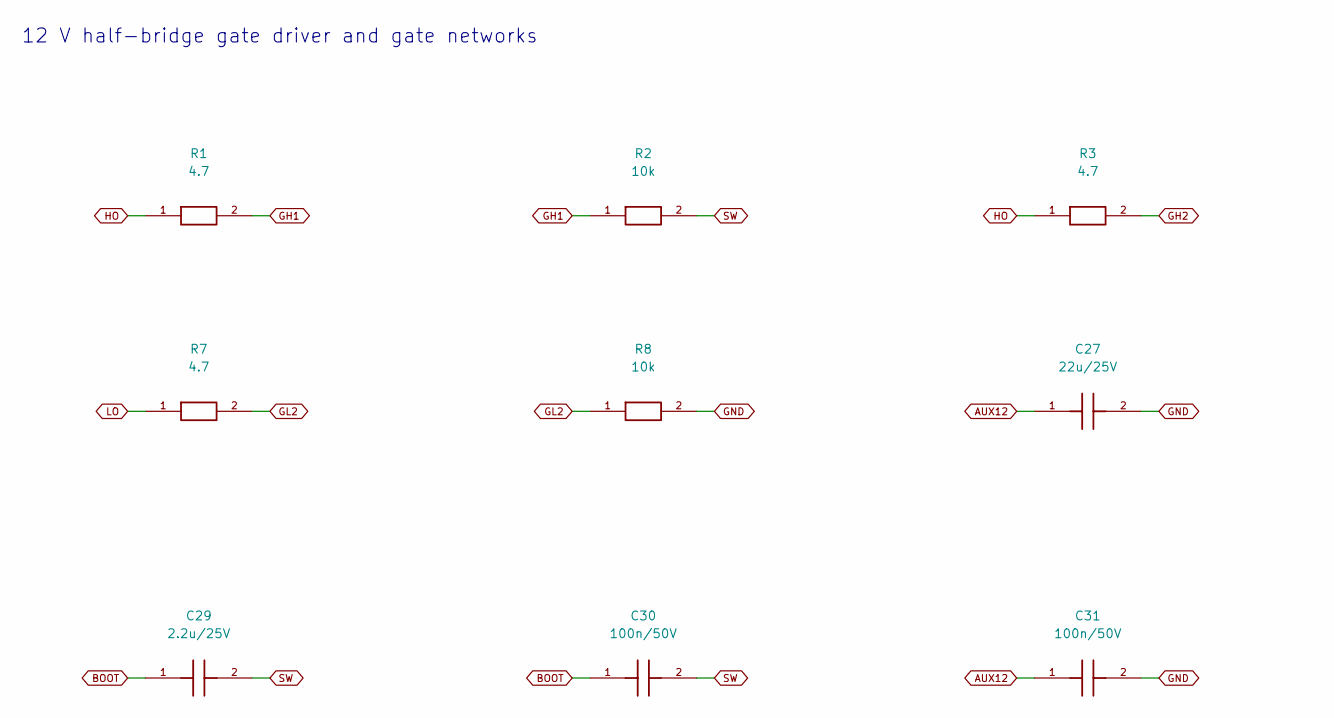
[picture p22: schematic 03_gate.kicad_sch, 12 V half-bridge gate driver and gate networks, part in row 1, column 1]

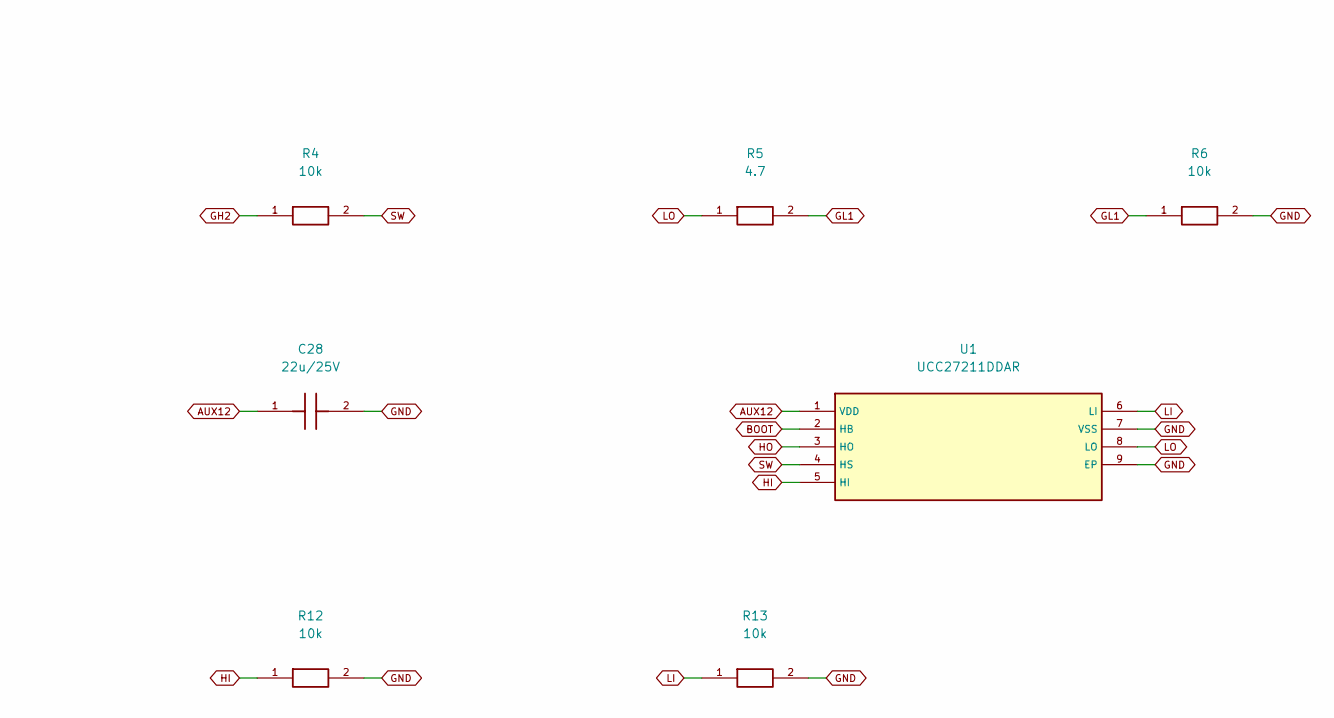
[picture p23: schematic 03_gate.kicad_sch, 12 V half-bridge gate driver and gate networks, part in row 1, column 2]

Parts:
C27, C28: 22u/25V; C_1210_3225Metric
C29: 2.2u/25V; C_0805_2012Metric
C30, C31: 100n/50V; C_0805_2012Metric
R1, R3, R5, R7: 4.7; R_0805_2012Metric
R2, R4, R6, R8, R12, R13: 10k; R_0805_2012Metric
U1: UCC27211DDAR; SOIC-8-1EP_3.9x4.9mm_P1.27mm_EP2.95x4.9mm_Mask2.71x3.4mm

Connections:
AUX12: C27.1, C28.1, C31.1, U1.1 (VDD); also elsewhere on the board
BOOT: C29.1, C30.1, U1.2 (HB)
GH1: R1.2, R2.1; also elsewhere on the board
GH2: R3.2, R4.1; also elsewhere on the board
GL1: R5.2, R6.1; also elsewhere on the board
GL2: R7.2, R8.1; also elsewhere on the board
GND: C27.2, C28.2, C31.2, R6.2, R8.2, R12.2, R13.2, U1.7 (VSS), U1.9 (EP); also elsewhere on the board
HI: R12.1, U1.5 (HI); also elsewhere on the board
HO: R1.1, R3.1, U1.3 (HO)
LI: R13.1, U1.6 (LI); also elsewhere on the board
LO: R5.1, R7.1, U1.8 (LO)
SW: C29.2, C30.2, R2.2, R4.2, U1.4 (HS); also elsewhere on the board

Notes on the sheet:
12 V half-bridge gate driver and gate networks

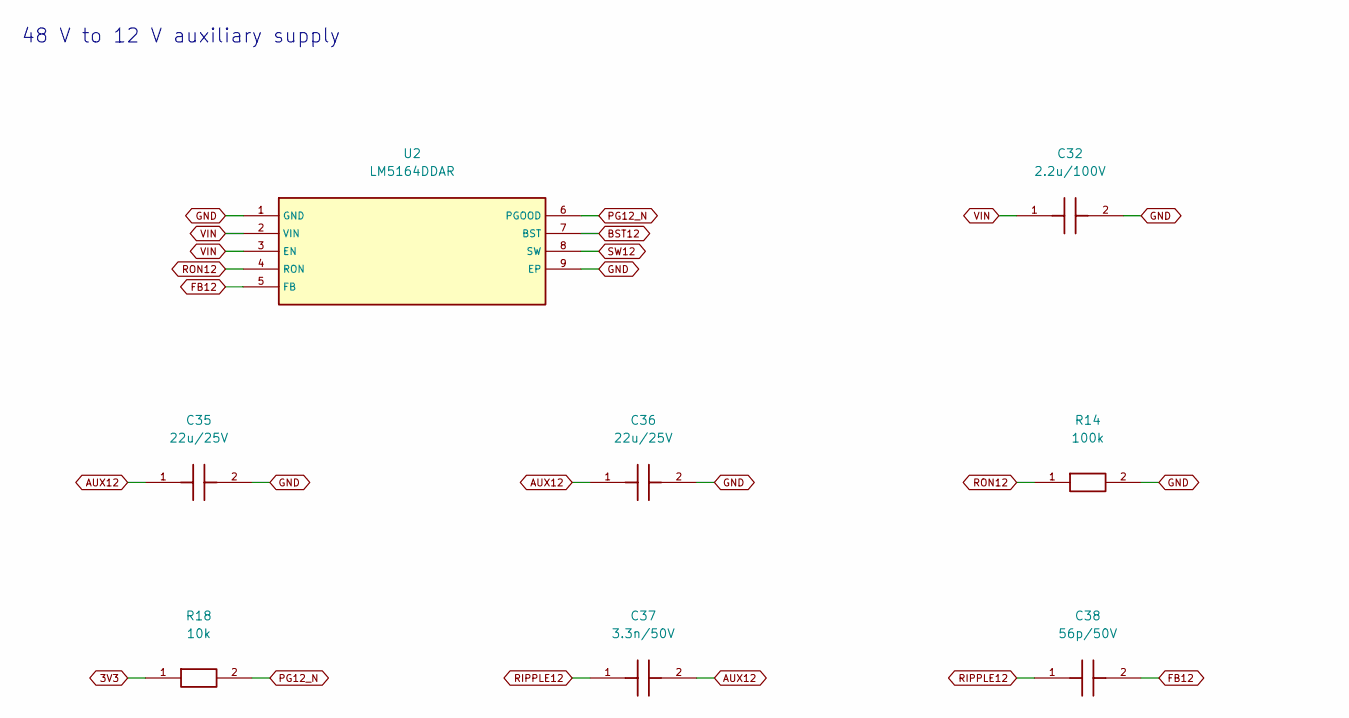
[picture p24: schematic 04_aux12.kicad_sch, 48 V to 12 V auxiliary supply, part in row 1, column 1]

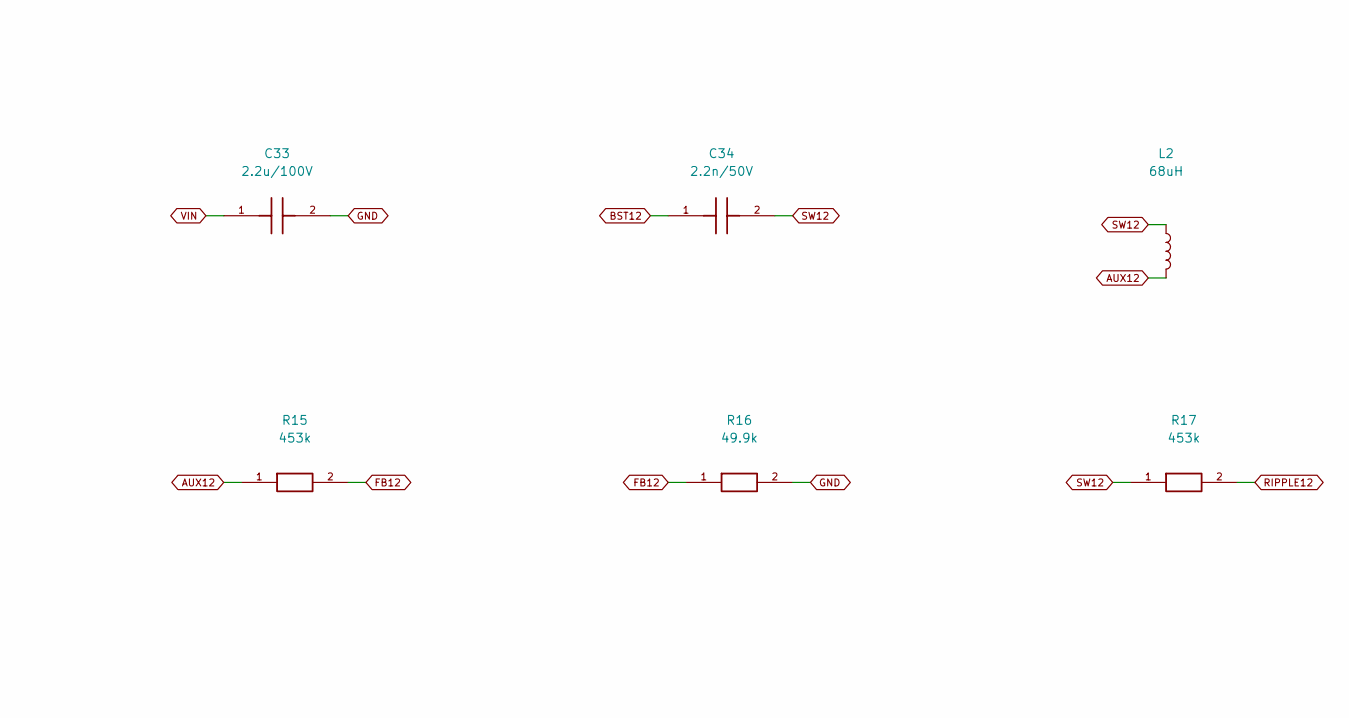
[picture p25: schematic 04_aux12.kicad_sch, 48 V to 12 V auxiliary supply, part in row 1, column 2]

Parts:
C32, C33: 2.2u/100V; C_1210_3225Metric
C34: 2.2n/50V; C_0805_2012Metric
C35, C36: 22u/25V; C_1210_3225Metric
C37: 3.3n/50V; C_0805_2012Metric
C38: 56p/50V; C_0805_2012Metric
L2: 68uH; L_Coilcraft_MSS1246T-XXX
R14: 100k; R_0805_2012Metric
R15, R17: 453k; R_0805_2012Metric
R16: 49.9k; R_0805_2012Metric
R18: 10k; R_0805_2012Metric
U2: LM5164DDAR; SOIC-8-1EP_3.9x4.9mm_P1.27mm_EP2.95x4.9mm_Mask2.71x3.4mm

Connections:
3V3: R18.1; also elsewhere on the board
AUX12: C35.1, C36.1, C37.2, L2.2, R15.1; also elsewhere on the board
BST12: C34.1, U2.7 (BST)
FB12: C38.2, R15.2, R16.1, U2.5 (FB)
GND: C32.2, C33.2, C35.2, C36.2, R14.2, R16.2, U2.1 (GND), U2.9 (EP); also elsewhere on the board
PG12_N: R18.2, U2.6 (PGOOD); also elsewhere on the board
RIPPLE12: C37.1, C38.1, R17.2
RON12: R14.1, U2.4 (RON)
SW12: C34.2, L2.1, R17.1, U2.8 (SW)
VIN: C32.1, C33.1, U2.2 (VIN), U2.3 (EN); also elsewhere on the board

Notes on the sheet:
48 V to 12 V auxiliary supply

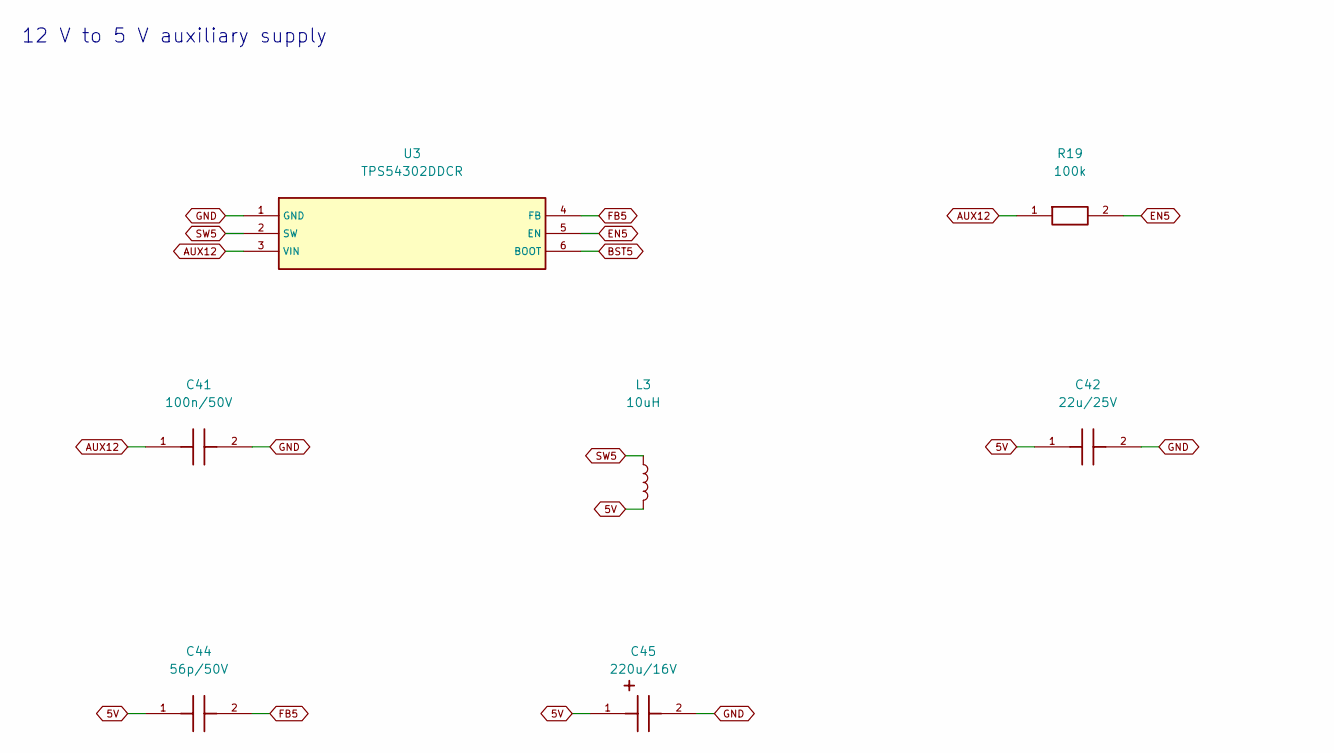
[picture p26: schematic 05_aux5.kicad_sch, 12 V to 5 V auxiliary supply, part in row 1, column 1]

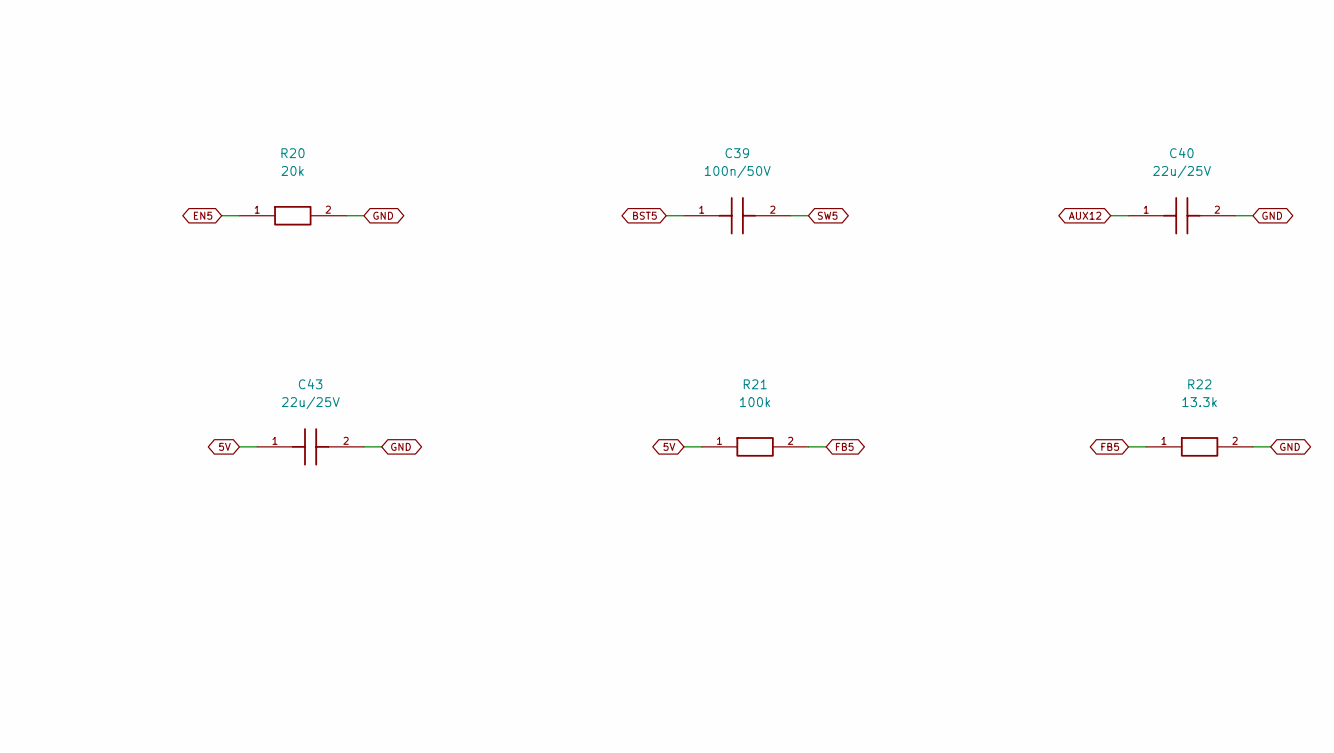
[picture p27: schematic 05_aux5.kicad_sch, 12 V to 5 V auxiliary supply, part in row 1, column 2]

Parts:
C39, C41: 100n/50V; C_0805_2012Metric
C40, C42, C43: 22u/25V; C_1210_3225Metric
C44: 56p/50V; C_0805_2012Metric
C45: 220u/16V; CP_Radial_D6.3mm_P2.50mm
L3: 10uH; L_Coilcraft_MSS1048-XXX
R19, R21: 100k; R_0805_2012Metric
R20: 20k; R_0805_2012Metric
R22: 13.3k; R_0805_2012Metric
U3: TPS54302DDCR; SOT-23-6

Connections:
5V: C42.1, C43.1, C44.1, C45.1, L3.2, R21.1; also elsewhere on the board
AUX12: C40.1, C41.1, R19.1, U3.3 (VIN); also elsewhere on the board
BST5: C39.1, U3.6 (BOOT)
EN5: R19.2, R20.1, U3.5 (EN)
FB5: C44.2, R21.2, R22.1, U3.4 (FB)
GND: C40.2, C41.2, C42.2, C43.2, C45.2, R20.2, R22.2, U3.1 (GND); also elsewhere on the board
SW5: C39.2, L3.1, U3.2 (SW)

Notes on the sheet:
12 V to 5 V auxiliary supply

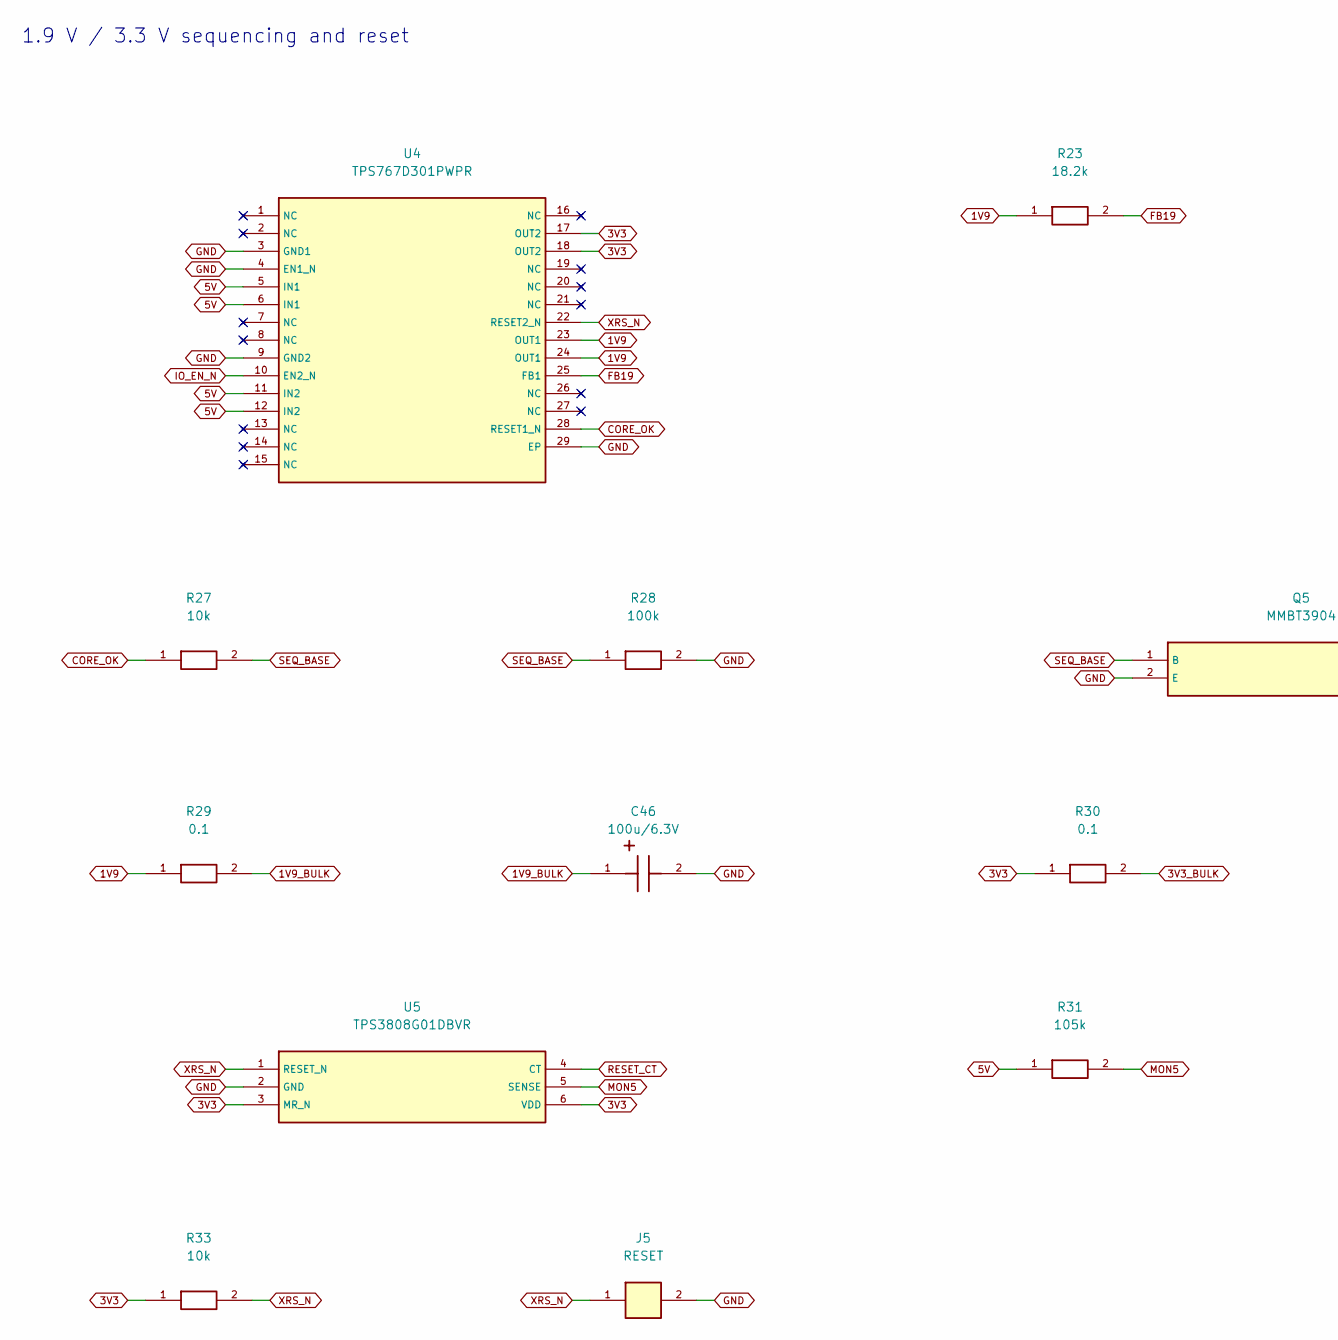
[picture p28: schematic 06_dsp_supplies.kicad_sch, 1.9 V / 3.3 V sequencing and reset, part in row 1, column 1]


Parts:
C46, C47: 100u/6.3V; CP_Elec_6.3x5.8
C48, C51: 100n/50V; C_0805_2012Metric
C49: 22u/25V; C_1210_3225Metric
C50: 10n/50V; C_0805_2012Metric
D2: BAT54; SOT-23
J5: RESET; PinHeader_1x02_P2.54mm_Vertical
Q5: MMBT3904; SOT-23
R23: 18.2k; R_0805_2012Metric
R24: 30.1k; R_0805_2012Metric
R25, R26, R27, R32, R33: 10k; R_0805_2012Metric
R28: 100k; R_0805_2012Metric
R29, R30: 0.1; R_0805_2012Metric
R31: 105k; R_0805_2012Metric
U4: TPS767D301PWPR; HTSSOP-28-1EP_4.4x9.7mm_P0.65mm_EP2.85x5.4mm
U5: TPS3808G01DBVR; SOT-23-6

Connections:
1V9: R23.1, R29.1, U4.23 (OUT1), U4.24 (OUT1); also elsewhere on the board
1V9_BULK: C46.1, R29.2
3V3: C51.1, R30.1, R33.1, U4.17 (OUT2), U4.18 (OUT2), U5.3 (MR_N), U5.6 (VDD); also elsewhere on the board
3V3_BULK: C47.1, R30.2
5V: C48.1, C49.1, R25.1, R26.1, R31.1, U4.5 (IN1), U4.6 (IN1), U4.11 (IN2), U4.12 (IN2); also elsewhere on the board
CORE_OK: D2.3 (K), R25.2, R27.1, U4.28 (RESET1_N)
FB19: R23.2, R24.1, U4.25 (FB1)
GND: C46.2, C47.2, C48.2, C49.2, C50.2, C51.2, J5.2, Q5.2 (E), R24.2, R28.2, R32.2, U4.3 (GND1), U4.4 (EN1_N), U4.9 (GND2), U4.29 (EP), U5.2 (GND); also elsewhere on the board
IO_EN_N: Q5.3 (C), R26.2, U4.10 (EN2_N)
MON5: R31.2, R32.1, U5.5 (SENSE)
RESET_CT: C50.1, U5.4 (CT)
SEQ_BASE: Q5.1 (B), R27.2, R28.1
XRS_N: D2.1 (A), J5.1, R33.2, U4.22 (RESET2_N), U5.1 (RESET_N); also elsewhere on the board

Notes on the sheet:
1.9 V / 3.3 V sequencing and reset

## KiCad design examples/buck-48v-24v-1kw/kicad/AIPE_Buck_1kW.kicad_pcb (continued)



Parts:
C52, C54, C55, C58, C59, C60, C61: 1n/50V; C_0805_2012Metric
C53, C56, C57: 100n/50V; C_0805_2012Metric
D3, D4, D5, D6, D7, D8, D9, D10: BAT54; SOT-23
R34, R35: 10; R_0805_2012Metric
R36: 121k; R_0805_2012Metric
R37, R39: 4.99k; R_0805_2012Metric
R38: 49.9k; R_0805_2012Metric
R40, R41, R42, R43: 100; R_0805_2012Metric
U6: INA240A1DR; SOIC-8_3.9x4.9mm_P1.27mm
U7: LM61CIM3/NOPB; SOT-23
U8: TLV9004IDR; SOIC-14_3.9x8.7mm_P1.27mm

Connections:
3V3: C53.1, C56.1, C57.1, D3.3 (K), D5.3 (K), D7.3 (K), D9.3 (K), U6.6 (VS), U7.1 (VS), U8.4 (V+); also elsewhere on the board
ADC_CURRENT: C60.1, D7.1 (A), D8.3 (K), R42.2; also elsewhere on the board
ADC_TEMP: C61.1, D9.1 (A), D10.3 (K), R43.2; also elsewhere on the board
ADC_VIN: C58.1, D3.1 (A), D4.3 (K), R40.2; also elsewhere on the board
ADC_VOUT: C59.1, D5.1 (A), D6.3 (K), R41.2; also elsewhere on the board
CURRENT_BUF: R42.1, U8.8 (OUT3), U8.9 (IN3-)
CURRENT_RAW: U6.5 (OUT), U8.10 (IN3+); also elsewhere on the board
GND: C53.2, C54.2, C55.2, C56.2, C57.2, C58.2, C59.2, C60.2, C61.2, D4.1 (A), D6.1 (A), D8.1 (A), D10.1 (A), R37.2, R39.2, U6.2 (GND), U6.3 (REF2), U6.7 (REF1), U7.3 (GND), U8.11 (V-); also elsewhere on the board
ISENSE_N: R35.1; also elsewhere on the board
ISENSE_N_F: C52.2, R35.2, U6.1 (IN-)
ISENSE_P: R34.1; also elsewhere on the board
ISENSE_P_F: C52.1, R34.2, U6.8 (IN+)
TEMP_BUF: R43.1, U8.13 (IN4-), U8.14 (OUT4)
TEMP_RAW: U7.2 (OUT), U8.12 (IN4+); also elsewhere on the board
VIN: R36.1; also elsewhere on the board
VIN_BUF: R40.1, U8.1 (OUT1), U8.2 (IN1-)
VIN_DIV: C54.1, R36.2, R37.1, U8.3 (IN1+); also elsewhere on the board
VOUT: R38.1; also elsewhere on the board
VOUT_BUF: R41.1, U8.6 (IN2-), U8.7 (OUT2)
VOUT_DIV: C55.1, R38.2, R39.1, U8.5 (IN2+); also elsewhere on the board

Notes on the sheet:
Current / voltage / temperature measurement

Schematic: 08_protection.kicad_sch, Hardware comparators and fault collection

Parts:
C62, C64, C65, C66, C67, C68: 100n/50V; C_0805_2012Metric
C63: 2.2u/25V; C_0805_2012Metric
D11, D12: BAT54; SOT-23
J6: STOP / external open-drain fault; PinHeader_1x02_P2.54mm_Vertical
R44: 1k; R_0805_2012Metric
R45: 24k; R_0805_2012Metric
R46: 10k; R_0805_2012Metric
R47: 15k; R_0805_2012Metric
R48: 51k; R_0805_2012Metric
R49: 62k; R_0805_2012Metric
R50: 4.7k; R_0805_2012Metric
U9: REF3125AIDBZR; SOT-23
U10, U11: LM2903BDR; SOIC-8_3.9x4.9mm_P1.27mm

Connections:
3V3: C62.1, R50.1, U9.1 (IN); also elsewhere on the board
5V: C67.1, C68.1, U10.8 (VCC), U11.8 (VCC); also elsewhere on the board
CURRENT_RAW: U10.2 (IN1-); also elsewhere on the board
FAULT_N: D11.1 (A), D12.1 (A), J6.1, R50.2, U10.1 (OUT1), U10.7 (OUT2), U11.1 (OUT1), U11.7 (OUT2); also elsewhere on the board
GND: C62.2, C63.2, C64.2, C65.2, C66.2, C67.2, C68.2, J6.2, R45.2, R47.2, R49.2, U9.3 (GND), U10.4 (GND), U11.4 (GND); also elsewhere on the board
OCP_REF: C64.1, R44.2, R45.1, U10.3 (IN1+)
OTP_REF: C65.1, R46.2, R47.1, U11.3 (IN1+)
PG12_N: D12.3 (K); also elsewhere on the board
REF2V5: C63.1, R44.1, R46.1, R48.1, U9.2 (OUT), U10.5 (IN2+)
TEMP_RAW: U11.2 (IN1-); also elsewhere on the board
UVLO_REF: C66.1, R48.2, R49.1, U11.6 (IN2-)
VIN_DIV: U11.5 (IN2+); also elsewhere on the board
VOUT_DIV: U10.6 (IN2-); also elsewhere on the board
XRS_N: D11.3 (K); also elsewhere on the board

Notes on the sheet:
Hardware comparators and fault collection

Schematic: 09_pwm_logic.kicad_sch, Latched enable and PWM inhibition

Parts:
C69, C70, C71, C72: 100n/50V; C_0805_2012Metric
R51, R52: 33; R_0805_2012Metric
R53, R54, R55: 10k; R_0805_2012Metric
U12: SN74LVC1G74DCTR; SSOP-8_2.95x2.8mm_P0.65mm
U13: SN74LVC1G86DBVR; SOT-23-5
U14: SN74LVC1G08DBVR; SOT-23-5
U15: SN74LVC2G08DCTR; SSOP-8_2.95x2.8mm_P0.65mm

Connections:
3V3: C69.1, C70.1, C71.1, C72.1, U12.2 (D), U12.7 (PRE_N), U12.8 (VCC), U13.5 (VCC), U14.5 (VCC), U15.8 (VCC); also elsewhere on the board
ARM: R55.1, U12.1 (CLK); also elsewhere on the board
ARMED: U12.5 (Q), U14.1 (A); also elsewhere on the board
FAULT_N: U12.6 (CLR_N); also elsewhere on the board
GATE_OK: U14.4 (Y), U15.2 (1B), U15.6 (2B)
GND: C69.2, C70.2, C71.2, C72.2, R53.2, R54.2, R55.2, U12.4 (GND), U13.3 (GND), U14.3 (GND), U15.4 (GND); also elsewhere on the board
HI: R51.2; also elsewhere on the board
HI_LOGIC: R51.1, U15.7 (1Y)
LI: R52.2; also elsewhere on the board
LI_LOGIC: R52.1, U15.3 (2Y)
PWM_EXCLUSIVE: U13.4 (Y), U14.2 (B)
PWM_H: R53.1, U13.1 (A), U15.1 (1A); also elsewhere on the board
PWM_L: R54.1, U13.2 (B), U15.5 (2A); also elsewhere on the board

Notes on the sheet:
Latched enable and PWM inhibition

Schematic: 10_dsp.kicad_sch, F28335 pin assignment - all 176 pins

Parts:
U16: TMS320F28335PGFA; LQFP-176_24x24mm_P0.5mm

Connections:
1V9: U16.4 (VDD), U16.15 (VDD), U16.23 (VDD), U16.29 (VDD), U16.31 (VDD1A18), U16.59 (VDD2A18), U16.61 (VDD), U16.101 (VDD), U16.109 (VDD), U16.117 (VDD), U16.126 (VDD), U16.139 (VDD), U16.146 (VDD), U16.154 (VDD), U16.167 (VDD); also elsewhere on the board
3V3: U16.9 (VDDIO), U16.34 (VDDA2), U16.45 (VDDAIO), U16.71 (VDDIO), U16.84 (VDD3VFL), U16.93 (VDDIO), U16.107 (VDDIO), U16.121 (VDDIO), U16.143 (VDDIO), U16.159 (VDDIO), U16.170 (VDDIO); also elsewhere on the board
ADCBIAS: U16.57 (ADCRESEXT); also elsewhere on the board
ADCREFM: U16.55 (ADCREFM); also elsewhere on the board
ADCREFP: U16.56 (ADCREFP); also elsewhere on the board
ADC_CURRENT: U16.40 (ADCINA2); also elsewhere on the board
ADC_TEMP: U16.39 (ADCINA3); also elsewhere on the board
ADC_VIN: U16.42 (ADCINA0); also elsewhere on the board
ADC_VOUT: U16.41 (ADCINA1); also elsewhere on the board
ARM: U16.7 (GPIO2); also elsewhere on the board
BOOT84: U16.169 (GPIO84); also elsewhere on the board
BOOT85: U16.172 (GPIO85); also elsewhere on the board
BOOT86: U16.173 (GPIO86); also elsewhere on the board
BOOT87: U16.174 (GPIO87); also elsewhere on the board
CLK30: U16.105 (XCLKIN); also elsewhere on the board
EMU0: U16.85 (EMU0); also elsewhere on the board
EMU1: U16.86 (EMU1); also elsewhere on the board
FAULT_N: U16.21 (GPIO12); also elsewhere on the board
GND: U16.3 (VSS), U16.8 (VSS), U16.14 (VSS), U16.22 (VSS), U16.30 (VSS), U16.32 (VSS1AGND), U16.33 (VSSA2), U16.35 (ADCINA7), U16.36 (ADCINA6), U16.37 (ADCINA5), U16.38 (ADCINA4), U16.43 (ADCLO), U16.44 (VSSAIO), U16.46 (ADCINB0), U16.47 (ADCINB1), U16.48 (ADCINB2), U16.49 (ADCINB3), U16.50 (ADCINB4), U16.51 (ADCINB5), U16.52 (ADCINB6), U16.53 (ADCINB7), U16.54 (ADCREFIN), U16.58 (VSS2AGND), U16.60 (VSS), U16.70 (VSS), U16.83 (VSS), U16.92 (VSS), U16.103 (VSS), U16.104 (X1), U16.106 (VSS), U16.108 (VSS), U16.118 (VSS), U16.120 (VSS), U16.125 (VSS), U16.140 (VSS), U16.144 (VSS), U16.147 (VSS), U16.155 (VSS), U16.160 (VSS), U16.166 (VSS), U16.171 (VSS); also elsewhere on the board
PWM_H: U16.5 (GPIO0); also elsewhere on the board
PWM_L: U16.6 (GPIO1); also elsewhere on the board
TCK: U16.87 (TCK); also elsewhere on the board
TDI: U16.76 (TDI); also elsewhere on the board
TDO: U16.77 (TDO); also elsewhere on the board
TMS: U16.79 (TMS); also elsewhere on the board
TRST: U16.78 (TRST); also elsewhere on the board
UART_RX: U16.141 (GPIO28); also elsewhere on the board
UART_TX: U16.2 (GPIO29); also elsewhere on the board
XRS_N: U16.80 (XRS); also elsewhere on the board

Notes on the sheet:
F28335 pin assignment - all 176 pins
Units: supply pins / ADC / connected digital pins / intentionally unused digital pins. TEST1, TEST2 and X2 are NC.

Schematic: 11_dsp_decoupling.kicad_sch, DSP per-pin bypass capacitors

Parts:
C73, C74, C75, C76, C77, C78, C79, C80, C81, C82, C83, C84, C85, C86, C87, C88, C89, C90, C91, C92, C93, C94, C95, C96, C97, C98: 100n/50V; C_0805_2012Metric
C99, C100, C101, C102: 2.2u/25V; C_0805_2012Metric

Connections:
1V9: C73.1, C75.1, C76.1, C77.1, C78.1, C81.1, C82.1, C86.1, C88.1, C89.1, C91.1, C92.1, C94.1, C95.1, C97.1, C99.1, C100.1; also elsewhere on the board
3V3: C74.1, C79.1, C80.1, C83.1, C84.1, C85.1, C87.1, C90.1, C93.1, C96.1, C98.1, C101.1, C102.1; also elsewhere on the board
GND: C73.2, C74.2, C75.2, C76.2, C77.2, C78.2, C79.2, C80.2, C81.2, C82.2, C83.2, C84.2, C85.2, C86.2, C87.2, C88.2, C89.2, C90.2, C91.2, C92.2, C93.2, C94.2, C95.2, C96.2, C97.2, C98.2, C99.2, C100.2, C101.2, C102.2; also elsewhere on the board

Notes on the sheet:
DSP per-pin bypass capacitors

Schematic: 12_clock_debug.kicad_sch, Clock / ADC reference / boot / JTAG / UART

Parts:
C103, C104: 2.2u/25V; C_0805_2012Metric
C105: 100n/50V; C_0805_2012Metric
J7: TI 14-pin JTAG; key pin 6 absent; PinHeader_2x07_P2.54mm_Vertical
J8: BOOT: 1-2 SCI / 2-3 or open Flash; PinHeader_1x03_P2.54mm_Vertical
J9: UART 3.3 V only; PinHeader_1x03_P2.54mm_Vertical
R56: 22k; R_0805_2012Metric
R57: 33; R_0805_2012Metric
R58, R59, R60, R61, R62, R63, R64, R65: 4.7k; R_0805_2012Metric
R66: 2.2k; R_0805_2012Metric
R67, R68: 10k; R_0805_2012Metric
Y1: 30MHz/3V3; Oscillator_SMD_SeikoEpson_SG8002CA-4Pin_7.0x5.0mm

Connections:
3V3: C105.1, J7.5, J8.3, R58.1, R59.1, R60.1, R61.1, R62.1, R63.1, R64.1, R65.1, R68.1, Y1.1 (OE), Y1.4 (VDD); also elsewhere on the board
ADCBIAS: R56.1; also elsewhere on the board
ADCREFM: C103.1; also elsewhere on the board
ADCREFP: C104.1; also elsewhere on the board
BOOT84: J8.2, R58.2; also elsewhere on the board
BOOT85: R59.2; also elsewhere on the board
BOOT86: R60.2; also elsewhere on the board
BOOT87: R61.2; also elsewhere on the board
CLK30: R57.2; also elsewhere on the board
CLK30_SOURCE: R57.1, Y1.3 (OUT)
EMU0: J7.13, R62.2; also elsewhere on the board
EMU1: J7.14, R63.2; also elsewhere on the board
GND: C103.2, C104.2, C105.2, J7.4, J7.8, J7.10, J7.12, J8.1, J9.3, R56.2, R66.2, R67.2, Y1.2 (GND); also elsewhere on the board
TCK: J7.9, J7.11, R67.1; also elsewhere on the board
TDI: J7.3, R65.2; also elsewhere on the board
TDO: J7.7; also elsewhere on the board
TMS: J7.1, R64.2; also elsewhere on the board
TRST: J7.2, R66.1; also elsewhere on the board
UART_RX: J9.2, R68.2; also elsewhere on the board
UART_TX: J9.1; also elsewhere on the board

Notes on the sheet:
Clock / ADC reference / boot / JTAG / UART

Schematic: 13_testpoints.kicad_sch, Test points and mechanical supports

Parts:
H1, H2, H3, H4, H5, H6, H7, H8: M3 support; MountingHole_3.2mm_M3
TP1: VIN; TestPoint_Pad_D2.0mm
TP2: VOUT; TestPoint_Pad_D2.0mm
TP3: GND; TestPoint_Pad_D2.0mm
TP4: AUX12; TestPoint_Pad_D2.0mm
TP5: 5V; TestPoint_Pad_D2.0mm
TP6: 3V3; TestPoint_Pad_D2.0mm
TP7: 1V9; TestPoint_Pad_D2.0mm
TP8: FAULT_N; TestPoint_Pad_D2.0mm
TP9: ARMED; TestPoint_Pad_D2.0mm
TP10: ADC_CURRENT; TestPoint_Pad_D2.0mm
TP11: ADC_VOUT; TestPoint_Pad_D2.0mm
TP12: ADC_VIN; TestPoint_Pad_D2.0mm

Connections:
1V9: TP7.1; also elsewhere on the board
3V3: TP6.1; also elsewhere on the board
5V: TP5.1; also elsewhere on the board
ADC_CURRENT: TP10.1; also elsewhere on the board
ADC_VIN: TP12.1; also elsewhere on the board
ADC_VOUT: TP11.1; also elsewhere on the board
ARMED: TP9.1; also elsewhere on the board
AUX12: TP4.1; also elsewhere on the board
FAULT_N: TP8.1; also elsewhere on the board
GND: TP3.1; also elsewhere on the board
VIN: TP1.1; also elsewhere on the board
VOUT: TP2.1; also elsewhere on the board

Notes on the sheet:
Test points and mechanical supports
Flags: input source, fuse output, inductor output, auxiliary outputs through inductors, and bootstrap diode supply. They state supply provenance for ERC; they do not prove voltage, current capacity, or protection.


Board: 6 copper layers, 300.0 x 220.0 mm, 240 parts (0 on the bottom side), 85 nets.

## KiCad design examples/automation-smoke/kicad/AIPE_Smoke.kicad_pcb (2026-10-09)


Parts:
J1: VIN_VOUT_GND; PinHeader_1x03_P2.54mm_Vertical
R1, R2: 10k; R_0805_2012Metric

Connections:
/GND: J1.3, R2.2
/VIN: J1.1, R1.1
/VOUT: J1.2, R1.2, R2.1


Board: 2 copper layers, 25.0 x 18.0 mm, 3 parts (0 on the bottom side), 3 nets.

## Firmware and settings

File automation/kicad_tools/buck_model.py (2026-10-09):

"""Electrical source of truth for the V1 converter; no CAD or implicit wiring."""
from __future__ import annotations

import csv
import json
from pathlib import Path

ROOT = Path(__file__).resolve().parents[2]
EXAMPLE = ROOT / "examples/buck-48v-24v-1kw"
SO8 = "Package_SO:SOIC-8_3.9x4.9mm_P1.27mm"
EP8 = "Package_SO:SOIC-8-1EP_3.9x4.9mm_P1.27mm_EP2.95x4.9mm_Mask2.71x3.4mm"
SOT = "Package_TO_SOT_SMD:SOT-23"
SOT5 = "Package_TO_SOT_SMD:SOT-23-5"
SOT6 = "Package_TO_SOT_SMD:SOT-23-6"

# Each pin declaration is number:name:type. Types retain meaningful ERC semantics.
IC = {
    "UCC27211DDAR": (EP8,"1:VDD:power_in 2:HB:power_in 3:HO:output 4:HS:passive 5:HI:input 6:LI:input 7:VSS:power_in 8:LO:output 9:EP:power_in","ucc27211"),
    "LM5164DDAR": (EP8,"1:GND:power_in 2:VIN:power_in 3:EN:input 4:RON:passive 5:FB:input 6:PGOOD:open_collector 7:BST:passive 8:SW:power_out 9:EP:power_in","lm5164"),
    "TPS54302DDCR": (SOT6,"1:GND:power_in 2:SW:power_out 3:VIN:power_in 4:FB:input 5:EN:input 6:BOOT:passive","tps54302"),
    "TPS767D301PWPR": ("Package_SO:HTSSOP-28-1EP_4.4x9.7mm_P0.65mm_EP2.85x5.4mm",
        "1:NC:no_connect 2:NC:no_connect 3:GND1:power_in 4:EN1_N:input 5:IN1:power_in 6:IN1:power_in 7:NC:no_connect 8:NC:no_connect 9:GND2:power_in 10:EN2_N:input 11:IN2:power_in 12:IN2:power_in 13:NC:no_connect 14:NC:no_connect 15:NC:no_connect 16:NC:no_connect 17:OUT2:power_out 18:OUT2:passive 19:NC:no_connect 20:NC:no_connect 21:NC:no_connect 22:RESET2_N:open_collector 23:OUT1:power_out 24:OUT1:passive 25:FB1:input 26:NC:no_connect 27:NC:no_connect 28:RESET1_N:open_collector 29:EP:power_in","tps767d3"),
    "INA240A1DR": (SO8,"1:IN-:input 2:GND:power_in 3:REF2:input 4:NC:no_connect 5:OUT:output 6:VS:power_in 7:REF1:input 8:IN+:input","ina240"),
    "LM2903BDR": (SO8,"1:OUT1:open_collector 2:IN1-:input 3:IN1+:input 4:GND:power_in 5:IN2+:input 6:IN2-:input 7:OUT2:open_collector 8:VCC:power_in","lm2903b"),
    "TLV9004IDR": ("Package_SO:SOIC-14_3.9x8.7mm_P1.27mm","1:OUT1:output 2:IN1-:input 3:IN1+:input 4:V+:power_in 5:IN2+:input 6:IN2-:input 7:OUT2:output 8:OUT3:output 9:IN3-:input 10:IN3+:input 11:V-:power_in 12:IN4+:input 13:IN4-:input 14:OUT4:output","tlv9004"),
    "REF3125AIDBZR": (SOT,"1:IN:power_in 2:OUT:power_out 3:GND:power_in","ref3125"),
    "LM61CIM3/NOPB": (SOT,"1:VS:power_in 2:OUT:output 3:GND:power_in","lm61"),
    "SN74LVC1G74DCTR": ("Package_SO:SSOP-8_2.95x2.8mm_P0.65mm","1:CLK:input 2:D:input 3:Q_N:output 4:GND:power_in 5:Q:output 6:CLR_N:input 7:PRE_N:input 8:VCC:power_in","sn74lvc1g74"),
    "SN74LVC2G08DCTR": ("Package_SO:SSOP-8_2.95x2.8mm_P0.65mm","1:1A:input 2:1B:input 3:2Y:output 4:GND:power_in 5:2A:input 6:2B:input 7:1Y:output 8:VCC:power_in","sn74lvc2g08"),
    "SN74LVC1G86DBVR": (SOT5,"1:A:input 2:B:input 3:GND:power_in 4:Y:output 5:VCC:power_in","sn74lvc1g86"),
    "SN74LVC1G08DBVR": (SOT5,"1:A:input 2:B:input 3:GND:power_in 4:Y:output 5:VCC:power_in","sn74lvc1g08"),
    "TPS3808G01DBVR": (SOT6,"1:RESET_N:open_collector 2:GND:power_in 3:MR_N:input 4:CT:passive 5:SENSE:input 6:VDD:power_in","tps3808"),
}


def pin_defs(text):
    return {n:dict(name=name,type=kind) for n,name,kind in (s.split(":") for s in text.split())}


class Circuit:
    def __init__(self):
        self.parts = []
        self.counters = {}

    def add(self, prefix, value, footprint, nets, *, page, kind="passive", mpn="", maker="", source="", definitions=None, ref=None, note="", xy=None):
        self.counters[prefix] = self.counters.get(prefix,0)+1
        ref = ref or prefix+str(self.counters[prefix])
        assert not any(p['ref']==ref for p in self.parts), ref
        nets = {str(k):v for k,v in nets.items()}
        definitions = definitions or {n:dict(name=n,type="passive") for n in nets}
        assert set(definitions) == set(nets), (ref, set(definitions)^set(nets))
        part = dict(ref=ref,value=value,footprint=footprint,nets=nets,page=page,kind=kind,
                    mpn=mpn,maker=maker,source=source,pins=definitions,note=note,xy=xy)
        self.parts.append(part)
        return part

    def resistor(self, value, a, b, page, note="", package="0805"):
        code = value.replace(".","R") if 'k' not in value and 'M' not in value else value.replace('k','K').replace('.','K')
        # Explicit decimal-resistance coding: 4.7k -> 4K7; 0.1 -> 0R1.
        if 'k' in value and '.' in value: code = value.replace('k','').replace('.','K')
        if value.startswith('0.'): code = '0R'+value[2:]
        if value.isdigit(): code += 'R'
        return self.add('R',value,f"Resistor_SMD:R_{package}_{'2012' if package=='0805' else '6332'}Metric",{1:a,2:b},page=page,kind='R',mpn=f"RC{package}FR-07{code}L",maker="Yageo",source="https://www.yageo.com/en/Chart/Download/pdf/RC0805",note=note)

    def cap(self, value, a, b, page, note=""):
        choices = {
            "100n/50V":("GRM21BR71H104KA01L","Murata","0805_2012Metric"),
            "2.2u/100V":("CGA6N3X7R2A225K230AB","TDK","1210_3225Metric"),
            "2.2u/25V":("GRM21BR71E225KA73L","Murata","0805_2012Metric"),
            "22u/25V":("TMK325B7226KMHT","Taiyo Yuden","1210_3225Metric"),
            "1n/50V":("C0805C102J5GACTU","KEMET","0805_2012Metric"),
            "2.2n/50V":("C0805C222K5RACTU","KEMET","0805_2012Metric"),
            "3.3n/50V":("C0805C332K5RACTU","KEMET","0805_2012Metric"),
            "56p/50V":("C0805C560J5GACTU","KEMET","0805_2012Metric"),
            "10n/50V":("C0805C103K5RACTU","KEMET","0805_2012Metric"),
        }
        mpn,maker,package=choices[value]
        return self.add('C',value,'Capacitor_SMD:C_'+package,{1:a,2:b},page=page,kind='C',mpn=mpn,maker=maker,note=note,
                        source="https://www.ti.com/lit/ds/symlink/lm5164.pdf" if value in ('2.2u/100V','22u/25V') else "Manufacturer series specification; exact order code requires BOM review")

    def ic(self, mpn, nets, page, note=""):
        footprint, declaration, source = IC[mpn]
        defs=pin_defs(declaration)
        nets={str(k):v for k,v in nets.items()}
        for n,p in defs.items():
            if p['type']=='no_connect': nets.setdefault(n,None)
        return self.add('U',mpn,footprint,nets,page=page,kind='IC',mpn=mpn,maker="Texas Instruments",source=source,definitions=defs,note=note)

    def header(self, count, nets, page, note="", rows=1):
        label=f"{rows}x{count//rows:02}"
        return self.add('J',note or label,f"Connector_PinHeader_2.54mm:PinHeader_{label}_P2.54mm_Vertical",nets,page=page,kind='J',maker='Samtec',mpn=f"TSW-{count//rows:03}-07-G-{'S' if rows==1 else 'D'}",source='https://www.samtec.com/products/tsw',note=note)

    def diode(self, cathode, anode, page, note=""):
        return self.add('D','BAT54','Package_TO_SOT_SMD:SOT-23',{1:anode,2:None,3:cathode},page=page,kind='IC',maker='Nexperia',mpn='BAT54,215',source='https://assets.nexperia.com/documents/data-sheet/BAT54_SER.pdf',definitions=pin_defs('1:A:passive 2:NC:no_connect 3:K:passive'),note=note)


def build():
    c=Circuit()
    for value,net in [('VIN+','VIN_RAW'),('VIN-','GND'),('VOUT+','VOUT'),('VOUT-','GND')]:
        c.add('J',value,'TerminalBlock_Wuerth:Wuerth_REDCUBE-THR_WP-THRSH_74651195_THR',{1:net},page='01_power',kind='J',mpn='74651195',maker='Wurth Elektronik',source='74651195',note='M5; 85 A at 20 C conditional on PCB and cable; support during torque')
    c.add('F','40A/70V','AIPE:MIDI_70V_M6_P30',{1:'VIN_RAW',2:'VIN'},page='01_power',mpn='4998040.M-NH',maker='Littelfuse',source='https://www.littelfuse.com/assetdocs/littelfuse-datasheet-4998-midihp70v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',note='Bolt-down; hardware and insulating support required')
    c.add('D','SMCJ54A','Diode_SMD:D_SMC',{1:'VIN',2:'GND'},page='01_power',kind='D',mpn='SMCJ54A-13-F',maker='Diodes Incorporated',source='https://www.diodes.com/part/view/SMCJ54A',note='54 V standoff; 87.1 V max specified pulse clamp, not hotplug qualification')
    for _ in range(14):
        c.add('C','470u/100V','Capacitor_THT:CP_Radial_D18.0mm_P7.50mm',{1:'VIN',2:'GND'},page='02_capacitors',kind='C',mpn='EKY-101ELL471MM25S',maker='Nippon Chemi-Con',source='https://www.chemi-con.co.jp/en/products/detail-condenser.php?part_number=EKY-101ELL471MM25S',note='1.75 Arms at 105 C / 100 kHz; 36 mohm impedance max at 20 C')
    for _ in range(8): c.cap('2.2u/100V','VIN','GND','01_power','Local commutation bypass; do not credit nominal capacitance under bias')
    for gate,drain,source in [('GH1','VIN','SW'),('GH2','VIN','SW'),('GL1','SW','GND'),('GL2','SW','GND')]:
        c.add('Q','CSD19536KCS','Package_TO_SOT_THT:TO-220-3_Vertical',{1:gate,2:drain,3:source},page='01_power',kind='Q',mpn='CSD19536KCS',maker='Texas Instruments',source='csd19536kcs',definitions=pin_defs('1:G:input 2:D:passive 3:S:passive'),note='Tab=drain. Individual insulated thermal interface required.')
        c.resistor('4.7','HO' if gate.startswith('GH') else 'LO',gate,'03_gate')
        c.resistor('10k',gate,source,'03_gate')
    c.add('L','10uH/83A','AIPE:IHXL2000VZ_10uH_Upright',{1:'SW',2:'IL_FORCE'},page='01_power',kind='L',mpn='IHXL2000VZEB100M3A',maker='Vishay',source='ihxl2000vz-3a',note='83 A thermal / 83 A at 20% L drop; 0.86 mohm max; custom support required')
    c.add('R','2m/6W/Kelvin','AIPE:CSS4J_4026_Kelvin',{1:'IL_FORCE',2:'VOUT',3:'ISENSE_P',4:'ISENSE_N'},page='01_power',kind='SHUNT',mpn='CSS4J-4026K-2L00F',maker='Bourns',source='css4j-4026',note='6 W at 70 C terminal; 1%; 4-terminal')
    for _ in range(4):
        c.add('C','1000u/50V','Capacitor_THT:CP_Radial_D16.0mm_P7.50mm',{1:'VOUT',2:'GND'},page='02_capacitors',kind='C',mpn='EKY-500ELL102ML25S',maker='Nippon Chemi-Con',source='https://www.chemi-con.co.jp/en/products/detail-condenser.php?part_number=EKY-500ELL102ML25S',note='2.555 Arms / 25 mohm impedance at 100 kHz')
    for _ in range(2): c.cap('22u/25V','AUX12','GND','03_gate')
    c.resistor('10k','VIN','GND','02_capacitors',package='2512',note='Input bleeder ~0.23 W nominal')
    c.resistor('2.4k','VOUT','GND','02_capacitors',package='2512',note='Output bleeder 0.24 W nominal')
    c.ic('UCC27211DDAR',{1:'AUX12',2:'BOOT',3:'HO',4:'SW',5:'HI',6:'LI',7:'GND',8:'LO',9:'GND'},'03_gate')
    c.cap('2.2u/25V','BOOT','SW','03_gate'); c.cap('100n/50V','BOOT','SW','03_gate')
    c.cap('100n/50V','AUX12','GND','03_gate')
    for net in ('HI','LI'): c.resistor('10k',net,'GND','03_gate')
    c.ic('LM5164DDAR',{1:'GND',2:'VIN',3:'VIN',4:'RON12',5:'FB12',6:'PG12_N',7:'BST12',8:'SW12',9:'GND'},'04_aux12')
    for _ in range(2): c.cap('2.2u/100V','VIN','GND','04_aux12')
    c.cap('2.2n/50V','BST12','SW12','04_aux12')
    c.add('L','68uH','Inductor_SMD:L_Coilcraft_MSS1246T-XXX',{1:'SW12',2:'AUX12'},page='04_aux12',kind='L',mpn='MSS1246T-683MLC',maker='Coilcraft',source='lm5164')
    for _ in range(2): c.cap('22u/25V','AUX12','GND','04_aux12')
    for value,a,b in [('100k','RON12','GND'),('453k','AUX12','FB12'),('49.9k','FB12','GND'),('453k','SW12','RIPPLE12'),('10k','3V3','PG12_N')]: c.resistor(value,a,b,'04_aux12')
    c.cap('3.3n/50V','RIPPLE12','AUX12','04_aux12'); c.cap('56p/50V','RIPPLE12','FB12','04_aux12')
    c.ic('TPS54302DDCR',{1:'GND',2:'SW5',3:'AUX12',4:'FB5',5:'EN5',6:'BST5'},'05_aux5')
    c.resistor('100k','AUX12','EN5','05_aux5'); c.resistor('20k','EN5','GND','05_aux5')
    c.cap('100n/50V','BST5','SW5','05_aux5')
    c.cap('22u/25V','AUX12','GND','05_aux5'); c.cap('100n/50V','AUX12','GND','05_aux5')
    c.add('L','10uH','Inductor_SMD:L_Coilcraft_MSS1048-XXX',{1:'SW5',2:'5V'},page='05_aux5',kind='L',mpn='MSS1048-103MLC',maker='Coilcraft',source='https://www.coilcraft.com/en-us/products/power/shielded-inductors/ferrite-drum/mss-mos/mss1048/mss1048-103/')
    for _ in range(2): c.cap('22u/25V','5V','GND','05_aux5')
    c.resistor('100k','5V','FB5','05_aux5'); c.resistor('13.3k','FB5','GND','05_aux5'); c.cap('56p/50V','5V','FB5','05_aux5')
    c.add('C','220u/16V','Capacitor_THT:CP_Radial_D6.3mm_P2.50mm',{1:'5V',2:'GND'},page='05_aux5',kind='C',mpn='EEU-FR1C221',maker='Panasonic',source='https://industrial.panasonic.com/ww/products/pt/aluminum-cap-lead/models/EEUFR1C221',note='Bulk hold-up; power-down timing needs measurement')
    c.ic('TPS767D301PWPR',{3:'GND',4:'GND',5:'5V',6:'5V',9:'GND',10:'IO_EN_N',11:'5V',12:'5V',17:'3V3',18:'3V3',22:'XRS_N',23:'1V9',24:'1V9',25:'FB19',28:'CORE_OK',29:'GND'},'06_dsp_supplies')
    # Datasheet reference = 1.1834 V; 18.2k / 30.1k sets 1.899 V.
    c.resistor('18.2k','1V9','FB19','06_dsp_supplies'); c.resistor('30.1k','FB19','GND','06_dsp_supplies')
    c.resistor('10k','5V','CORE_OK','06_dsp_supplies'); c.resistor('10k','5V','IO_EN_N','06_dsp_supplies')
    c.resistor('10k','CORE_OK','SEQ_BASE','06_dsp_supplies'); c.resistor('100k','SEQ_BASE','GND','06_dsp_supplies')
    c.add('Q','MMBT3904','Package_TO_SOT_SMD:SOT-23',{1:'SEQ_BASE',2:'GND',3:'IO_EN_N'},page='06_dsp_supplies',kind='IC',mpn='MMBT3904,215',maker='Nexperia',source='https://assets.nexperia.com/documents/data-sheet/MMBT3904.pdf',definitions=pin_defs('1:B:input 2:E:passive 3:C:open_collector'))
    c.diode('CORE_OK','XRS_N','06_dsp_supplies','Core failure asserts reset without 5 V pull-up on DSP')
    for rail in ('1V9','3V3'):
        c.resistor('0.1',rail,rail+'_BULK','06_dsp_supplies','Explicit output-capacitor ESR for LDO stability')
        c.add('C','100u/6.3V','Capacitor_SMD:CP_Elec_6.3x5.8',{1:rail+'_BULK',2:'GND'},page='06_dsp_supplies',kind='C',mpn='6SVP100M',maker='Panasonic',source='https://industrial.panasonic.com/ww/products/pt/os-con/models/6SVP100M',note='Low ESR polymer in series with 0.1 ohm; verify LDO stability')
    c.cap('100n/50V','5V','GND','06_dsp_supplies'); c.cap('22u/25V','5V','GND','06_dsp_supplies')
    c.ic('TPS3808G01DBVR',{1:'XRS_N',2:'GND',3:'3V3',4:'RESET_CT',5:'MON5',6:'3V3'},'06_dsp_supplies')
    c.resistor('105k','5V','MON5','06_dsp_supplies'); c.resistor('10k','MON5','GND','06_dsp_supplies')
    c.cap('10n/50V','RESET_CT','GND','06_dsp_supplies'); c.cap('100n/50V','3V3','GND','06_dsp_supplies')
    c.resistor('10k','3V3','XRS_N','06_dsp_supplies')
    c.header(2,{1:'XRS_N',2:'GND'},'06_dsp_supplies','RESET')

    # Sense/protection nets retain distinct Kelvin force/sense connections.
    c.ic('INA240A1DR',{1:'ISENSE_N_F',2:'GND',3:'GND',5:'CURRENT_RAW',6:'3V3',7:'GND',8:'ISENSE_P_F'},'07_sensing')
    c.resistor('10','ISENSE_P','ISENSE_P_F','07_sensing'); c.resistor('10','ISENSE_N','ISENSE_N_F','07_sensing')
    c.cap('1n/50V','ISENSE_P_F','ISENSE_N_F','07_sensing'); c.cap('100n/50V','3V3','GND','07_sensing')
    c.resistor('121k','VIN','VIN_DIV','07_sensing'); c.resistor('4.99k','VIN_DIV','GND','07_sensing'); c.cap('1n/50V','VIN_DIV','GND','07_sensing')
    c.resistor('49.9k','VOUT','VOUT_DIV','07_sensing'); c.resistor('4.99k','VOUT_DIV','GND','07_sensing'); c.cap('1n/50V','VOUT_DIV','GND','07_sensing')
    c.ic('LM61CIM3/NOPB',{1:'3V3',2:'TEMP_RAW',3:'GND'},'07_sensing','Place adjacent to the low-side MOSFET area')
    c.cap('100n/50V','3V3','GND','07_sensing')
    c.ic('TLV9004IDR',{1:'VIN_BUF',2:'VIN_BUF',3:'VIN_DIV',4:'3V3',5:'VOUT_DIV',6:'VOUT_BUF',7:'VOUT_BUF',8:'CURRENT_BUF',9:'CURRENT_BUF',10:'CURRENT_RAW',11:'GND',12:'TEMP_RAW',13:'TEMP_BUF',14:'TEMP_BUF'},'07_sensing')
    c.cap('100n/50V','3V3','GND','07_sensing')
    for signal in ('VIN','VOUT','CURRENT','TEMP'):
        c.resistor('100',signal+'_BUF','ADC_'+signal,'07_sensing')
        c.cap('1n/50V','ADC_'+signal,'GND','07_sensing')
        c.diode('3V3','ADC_'+signal,'07_sensing','ADC positive clamp; 3 V full-scale, rail clamp is not a precision limiter')
        c.diode('ADC_'+signal,'GND','07_sensing','ADC negative clamp')
    c.ic('REF3125AIDBZR',{1:'3V3',2:'REF2V5',3:'GND'},'08_protection')
    c.cap('100n/50V','3V3','GND','08_protection'); c.cap('2.2u/25V','REF2V5','GND','08_protection')
    for top,bot,net in [('1k','24k','OCP_REF'),('10k','15k','OTP_REF'),('51k','62k','UVLO_REF')]:
        c.resistor(top,'REF2V5',net,'08_protection'); c.resistor(bot,net,'GND','08_protection'); c.cap('100n/50V',net,'GND','08_protection')
    c.ic('LM2903BDR',{1:'FAULT_N',2:'CURRENT_RAW',3:'OCP_REF',4:'GND',5:'REF2V5',6:'VOUT_DIV',7:'FAULT_N',8:'5V'},'08_protection')
    c.ic('LM2903BDR',{1:'FAULT_N',2:'TEMP_RAW',3:'OTP_REF',4:'GND',5:'VIN_DIV',6:'UVLO_REF',7:'FAULT_N',8:'5V'},'08_protection')
    for _ in range(2): c.cap('100n/50V','5V','GND','08_protection')
    c.resistor('4.7k','3V3','FAULT_N','08_protection')
    c.diode('XRS_N','FAULT_N','08_protection','Reset also clears gate-enable latch')
    c.diode('PG12_N','FAULT_N','08_protection','12 V power-good failure also clears gate-enable latch')
    c.header(2,{1:'FAULT_N',2:'GND'},'08_protection','STOP / external open-drain fault')
    c.ic('SN74LVC1G74DCTR',{1:'ARM',2:'3V3',3:None,4:'GND',5:'ARMED',6:'FAULT_N',7:'3V3',8:'3V3'},'09_pwm_logic')
    c.ic('SN74LVC1G86DBVR',{1:'PWM_H',2:'PWM_L',3:'GND',4:'PWM_EXCLUSIVE',5:'3V3'},'09_pwm_logic')
    c.ic('SN74LVC1G08DBVR',{1:'ARMED',2:'PWM_EXCLUSIVE',3:'GND',4:'GATE_OK',5:'3V3'},'09_pwm_logic')
    c.ic('SN74LVC2G08DCTR',{1:'PWM_H',2:'GATE_OK',3:'LI_LOGIC',4:'GND',5:'PWM_L',6:'GATE_OK',7:'HI_LOGIC',8:'3V3'},'09_pwm_logic')
    for a,b in [('HI_LOGIC','HI'),('LI_LOGIC','LI')]: c.resistor('33',a,b,'09_pwm_logic')
    for net in ('PWM_H','PWM_L','ARM'): c.resistor('10k',net,'GND','09_pwm_logic')
    for _ in range(4): c.cap('100n/50V','3V3','GND','09_pwm_logic')

    dsp_defs={}; dsp_nets={}
    with (EXAMPLE/'components/tms320f28335_pgf_pins.csv').open() as stream:
        for pin in csv.DictReader(stream):
            n,name=pin['pin'],pin['name']
            kind='bidirectional' if name.startswith('GPIO') or name in ('EMU0','EMU1') else 'input'
            if name.startswith('VDD'): kind='power_in'
            if name.startswith('VSS'): kind='power_in'
            if name in ('TEST1','TEST2'): kind='no_connect'
            if name in ('X2','XRD','XCLKOUT','ADCREFP','ADCREFM','TDO'): kind='output'
            if name=='XRS': kind='open_collector'
            dsp_defs[n]=dict(name=name,type=kind)
            net=None
            if name=='VDD' or name in ('VDD1A18','VDD2A18'): net='1V9'
            elif name.startswith('VDD'): net='3V3'
            elif name.startswith('VSS') or name in ('ADCLO','ADCREFIN','X1'): net='GND'
            elif name.startswith('ADCIN'): net='GND'
            dsp_nets[n]=net
    dsp_nets.update({'5':'PWM_H','6':'PWM_L','7':'ARM','21':'FAULT_N','2':'UART_TX','141':'UART_RX',
                     '42':'ADC_VIN','41':'ADC_VOUT','40':'ADC_CURRENT','39':'ADC_TEMP','55':'ADCREFM','56':'ADCREFP','57':'ADCBIAS',
                     '76':'TDI','77':'TDO','78':'TRST','79':'TMS','80':'XRS_N','85':'EMU0','86':'EMU1','87':'TCK','105':'CLK30',
                     '169':'BOOT84','172':'BOOT85','173':'BOOT86','174':'BOOT87'})
    c.add('U','TMS320F28335PGFA','Package_QFP:LQFP-176_24x24mm_P0.5mm',dsp_nets,page='10_dsp',kind='DSP',mpn='TMS320F28335PGFA',maker='Texas Instruments',source='tms320f28335',definitions=dsp_defs)
    for n,net in dsp_nets.items():
        if dsp_defs[n]['name'].startswith('VDD'):
            p=c.cap('100n/50V',net,'GND','11_dsp_decoupling',f'DSP pin {n} {dsp_defs[n]["name"]}; place at pin')
            p['near_dsp_pin']=n
    for net in ('1V9','1V9','3V3','3V3'): c.cap('2.2u/25V',net,'GND','11_dsp_decoupling')
    for net in ('ADCREFM','ADCREFP'): c.cap('2.2u/25V',net,'GND','12_clock_debug','ADC reference low-ESR bypass')
    c.resistor('22k','ADCBIAS','GND','12_clock_debug')
    c.add('Y','30MHz/3V3','Oscillator:Oscillator_SMD_SeikoEpson_SG8002CA-4Pin_7.0x5.0mm',{1:'3V3',2:'GND',3:'CLK30_SOURCE',4:'3V3'},page='12_clock_debug',kind='IC',mpn='ASV-30.000MHZ-EJ-T',maker='Abracon',source='asv',definitions=pin_defs('1:OE:input 2:GND:power_in 3:OUT:output 4:VDD:power_in'))
    c.cap('100n/50V','3V3','GND','12_clock_debug'); c.resistor('33','CLK30_SOURCE','CLK30','12_clock_debug')
    for net in ('BOOT84','BOOT85','BOOT86','BOOT87','EMU0','EMU1','TMS','TDI'): c.resistor('4.7k','3V3',net,'12_clock_debug')
    c.resistor('2.2k','TRST','GND','12_clock_debug'); c.resistor('10k','TCK','GND','12_clock_debug')
    c.header(14,{1:'TMS',2:'TRST',3:'TDI',4:'GND',5:'3V3',6:None,7:'TDO',8:'GND',9:'TCK',10:'GND',11:'TCK',12:'GND',13:'EMU0',14:'EMU1'},'12_clock_debug','TI 14-pin JTAG; key pin 6 absent',rows=2)
    c.header(3,{1:'GND',2:'BOOT84',3:'3V3'},'12_clock_debug','BOOT: 1-2 SCI / 2-3 or open Flash')
    c.header(3,{1:'UART_TX',2:'UART_RX',3:'GND'},'12_clock_debug','UART 3.3 V only')
    c.resistor('10k','3V3','UART_RX','12_clock_debug')
    for net in ('VIN','VOUT','GND','AUX12','5V','3V3','1V9','FAULT_N','ARMED','ADC_CURRENT','ADC_VOUT','ADC_VIN'):
        c.add('TP',net,'TestPoint:TestPoint_Pad_D2.0mm',{1:net},page='13_testpoints',kind='TP',note='Bare PCB test point; no purchased component')
    for _ in range(8): c.add('H','M3 support','MountingHole:MountingHole_3.2mm_M3',{},page='13_testpoints',kind='H',note='Mechanical NPTH; standoff hardware specified in assembly notes')
    return c


def write_model():
    circuit=build()
    (EXAMPLE/'design/circuit.json').write_text(json.dumps(circuit.parts,indent=2)+'\n')
    fields=['reference','value','manufacturer','part_number','footprint','datasheet','note']
    for name in ('bom.csv','component_selection.csv'):
        with (EXAMPLE/'components'/name).open('w',newline='',encoding='utf8') as stream:
            writer=csv.DictWriter(stream,fieldnames=fields);writer.writeheader()
            for p in circuit.parts:
                writer.writerow(dict(reference=p['ref'],value=p['value'],manufacturer=p['maker'],part_number=p['mpn'],footprint=p['footprint'],datasheet=p['source'],note=p['note']))
    print(f"Electrical model: {len(circuit.parts)} parts, {len({n for p in circuit.parts for n in p['nets'].values() if n})} nets")


if __name__=='__main__': write_model()

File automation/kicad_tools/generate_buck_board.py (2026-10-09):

"""Deterministic functional placement for the integrated six-layer prototype."""
from __future__ import annotations

import json
import math
import sys
import subprocess
import xml.etree.ElementTree as ET
from pathlib import Path

ROOT=Path(__file__).resolve().parents[2]
sys.path.insert(0,str(ROOT))
from automation.kicad_tools.buck_model import build,EXAMPLE
from automation.kicad_tools.buck_footprints import prepare
from automation.setup.detect_kicad import find_kicad_cli

NAME='AIPE_Buck_1kW'
WIDTH,HEIGHT=300.0,220.0


def generate():
    import pcbnew as pcb
    import numpy as np
    prepare()
    parts=build().parts
    mapping=json.loads((EXAMPLE/'design/schematic_mapping.json').read_text())['paths']
    board=pcb.BOARD();board.SetCopperLayerCount(6)
    title=board.GetTitleBlock();title.SetTitle('AIPE 48V to 24V / 1kW');title.SetRevision('V1')
    title.SetComment(0,'AI-GENERATED ENGINEERING PROTOTYPE - HUMAN REVIEW REQUIRED')
    board.GetDesignSettings().SetBoardThickness(pcb.FromMM(2.0))
    netlist=EXAMPLE/'verification/schematic_netlist.xml'
    netlist.parent.mkdir(parents=True,exist_ok=True)
    subprocess.run([str(find_kicad_cli()),'sch','export','netlist','--format','kicadxml','--output',str(netlist),str(EXAMPLE/'kicad'/(NAME+'.kicad_sch'))],check=True,capture_output=True)
    tree=ET.parse(netlist).getroot()
    cad_pin_nets={(node.attrib['ref'],node.attrib['pin']):net.attrib['name'] for net in tree.findall('nets/net') for node in net.findall('node')}
    nets={}
    for name in sorted(set(cad_pin_nets.values())):
        net=pcb.NETINFO_ITEM(board,name); board.Add(net);nets[name]=net

    def point(x,y): return pcb.VECTOR2I(pcb.FromMM(x),pcb.FromMM(y))

    footprints={}; byref={p['ref']:p for p in parts}
    for p in parts:
        lib,name=p['footprint'].split(':')
        fp=pcb.FootprintLoad(str(EXAMPLE/'kicad/libraries'/(lib+'.pretty')),name)
        if fp is None:raise ValueError(p['footprint'])
        fp.SetFPID(pcb.LIB_ID(lib,name)); fp.SetReference(p['ref']);fp.SetValue(p['value'])
        fp.SetPath(pcb.KIID_PATH(mapping[p['ref']]))
        fp.Value().SetVisible(False)
        fp.Reference().SetLayer(pcb.F_Fab)
        if any(isinstance(g,pcb.PCB_TEXT) and g.GetText()=='${REFERENCE}' for g in fp.GraphicalItems()):
            fp.Reference().SetVisible(False)
        fp.Reference().SetTextSize(point(1,1));fp.Reference().SetTextThickness(pcb.FromMM(0.15))
        # Package drawings remain unchanged. Electrical pad mapping is explicit.
        seen=set()
        for pad in fp.Pads():
            n=pad.GetNumber()
            if not n:continue
            if n not in p['nets']:raise ValueError((p['ref'],'unexpected pad',n))
            seen.add(n)
            if (p['ref'],n) in cad_pin_nets:pad.SetNet(nets[cad_pin_nets[p['ref'],n]])
        if seen != set(p['nets']):raise ValueError((p['ref'],'missing pads',set(p['nets'])-seen))
        board.Add(fp); footprints[p['ref']]=fp

    occupied=[]; placements={}
    def bounds(fp):
        hull=fp.GetBoundingHull()
        box=hull.BBox()
        return [pcb.ToMM(box.GetX()),pcb.ToMM(box.GetY()),pcb.ToMM(box.GetRight()),pcb.ToMM(box.GetBottom())]

    def overlaps(a,b,gap=0.5):
        return a[0]<b[2]+gap and a[2]>b[0]-gap and a[1]<b[3]+gap and a[3]>b[1]-gap

    def place(ref,x,y,angle=0,check=True):
        fp=footprints[ref]; fp.SetOrientationDegrees(angle);fp.SetPosition(point(x,y))
        bb=bounds(fp)
        if check:
            for other,box in occupied:
                if overlaps(bb,box):raise ValueError(('placement overlap',ref,other,bb,box))
        placements[ref]=dict(x=x,y=y,angle=angle,bbox=bb)
        occupied.append((ref,bb))
        return bb

    fixed={'J1':(15,15),'J2':(12,104),'J3':(280,40),'J4':(280,90),
        'F1':(55,15),'D1':(84,15),'Q1':(112,42),'Q2':(126,42),
        'Q3':(112,55),'Q4':(126,55),'L1':(165,45),'R9':(207,45),
        'U1':(123,48.1),'U2':(34,143),'U3':(81,143),'U4':(125,143),
        'U5':(147,131),'U6':(210,68),'U7':(128,62),'U8':(223,124),
        'U9':(251,139),'U10':(256,157),'U11':(274,157),
        'U12':(126,91),'U13':(143,89),'U14':(143,97),'U15':(126,101),
        'U16':(181,173),'Y1':(206,172),
        'R1':(109,46),'R2':(107.5,50),'R3':(135,46),'R4':(137,50),
        'R5':(109,59),'R6':(107.5,63),'R7':(135,59),'R8':(137,63),
        'C27':(111,78),'C28':(121,78),
        'L2':(47,146),'L3':(93,146),
        'J5':(151,145),'J6':(275,140),'J7':(221,191),'J8':(240,206),'J9':(270,206)}
    # Verify device identities before relying on these physical anchors.
    assert byref['U16']['kind']=='DSP' and byref['U6']['mpn']=='INA240A1DR'
    assert byref['U7']['mpn'].startswith('LM61') and byref['U15']['mpn'].startswith('SN74LVC2G08')
    for ref,xy in fixed.items():place(ref,*xy,angle=90 if ref in {f'R{i}' for i in range(1,9)} else 0)
    for i in range(14):
        col=i%4;row=i//4
        place('C'+str(i+1),30+col*21,39+row*21)
    for i in range(8):place('C'+str(15+i),109+(i%4)*7,31 if i<4 else 71)
    for i in range(4):place('C'+str(23+i),237+(i%2)*23,32+(i//2)*25)
    holes=[(4,4),(295,5),(5,215),(150,215),(295,215),(136,24),(193,24),(165,76)]
    for i,xy in enumerate(holes,1):place('H'+str(i),*xy)

    # Each partition has clear physical intent. Candidates minimize pin-to-pin
    # connection length inside that partition while respecting courtyards.
    regions={
        '02_capacitors':(18,113,98,124),
        '03_gate':(103,26,142,80),
        '04_aux12':(18,128,67,171),
        '05_aux5':(70,128,108,176),
        '06_dsp_supplies':(112,118,157,165),
        '07_sensing':(203,68,247,145),
        '08_protection':(243,130,288,187),
        '09_pwm_logic':(108,80,156,110),
        '11_dsp_decoupling':(156,147,207,200),
        '12_clock_debug':(152,152,248,211),
        '13_testpoints':(18,181,288,211),
    }
    def anchors(part):
        result=[]
        for n in part['nets'].values():
            if not n or n=='GND':continue
            for ref in placements:
                other=byref[ref]
                if n not in other['nets'].values():continue
                # IC supply pin dominates bypass location; other rails must not
                # pull a control capacitor back into the power section.
                if other['page']!=part['page'] and part['kind']!='TP':continue
                for pad in footprints[ref].Pads():
                    if pad.GetNetname()==n:
                        x,y=pcb.ToMM(pad.GetPosition())
                        result.append((x,y,4 if other['kind'] in ('IC','DSP') else 1))
        return result
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

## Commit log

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2026-10-09 test: validate KiCad 10 automation with routed smoke board
    [AIPE_Smoke-B_Cu.gbl, AIPE_Smoke-B_Mask.gbs, AIPE_Smoke-B_Paste.gbp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]
2026-10-09 feat: document converter calculations and manufacturer references
    [tms320f28335_pgf_pins.csv]
2026-10-09 feat: generate complete 1kW converter schematic and verify ERC
    [01_power.kicad_sch, 02_capacitors.kicad_sch, 03_gate.kicad_sch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]
2026-10-09 feat: complete six-layer power PCB routing and pass native DRC
    [01_power.kicad_sch, 03_gate.kicad_sch, 04_aux12.kicad_sch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]
2026-10-09 docs: complete V1 engineering review and verified manufacturing package
    [01_power.kicad_sch, 02_capacitors.kicad_sch, 03_gate.kicad_sch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]
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2026-10-09 release: freeze buck 1kW V1 review prototype
    [01_power.kicad_sch, 02_capacitors.kicad_sch, 03_gate.kicad_sch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]
2026-10-09 knowledge: reference acquisition and inspection pipeline
    Add a standard-library pipeline that downloads manufacturer reference
    material listed in curated reference records, validates file types,
    records URL/revision/date/size/SHA-256 per document, and inspects archives
    (safe extraction, format inventory, PDF text, XLSX to CSV) into a Git-ignored
    cache. Allegro pstxnet.dat and ODB++ readers let knowledge claims be checked
    against the manufacturers' own netlists.
    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
2026-10-09 knowledge: analyses, skills, circuit blocks, components and rules
    Add schemas and the first extracted engineering knowledge:
    - four reference analyses answering what/why/problem/applicability/
    evidence/reuse/verification for each important design decision;
    - SKILL-001..006 (SiC gate driver, gate-driver layout, DC-link capacitors,
    isolated gate bias, sensing, thermal placement) as Markdown with JSON
    indexes;
    - 13 circuit building blocks with ports by isolation domain, required parts,
    calculations and validation status;
    - 19 component records with datasheet-sourced parameters, verified URLs and
    only source-named alternatives;
    - 43 engineering rules split into hard constraints, optim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
2026-10-09 knowledge: validation, evidence checks, retrieval and tests
    - schema_check: stdlib JSON Schema subset that refuses unknown keywords;
    - validate: schemas, cross-references, acquisition traceability, rule
    policy (no single-reference hard constraints, limits need a non-instance
    basis, status claims need passing checks) and part-number presence in the
    cached manufacturer files;
    - check_evidence: 26 checks recomputing cited calculations and confirming
    netlist claims (24 pass, 2 computed for review; netlist checks report
    skipped without the cache);
    - query: BM25 retrieval over skills, rules, blocks, components and reference
    decisions with JSON output for the future Orchestrator, plus a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
2026-10-10 feat(v2): bootstrap 5 kW SiC buck example with requirements and verified environment
    Start the second AIPE benchmark (400 V to 200 V, 5 kW, 50 kHz, Wolfspeed SiC,
    TMS320F28335) under examples/sic-buck-400v-200v-5kw on branch feat/sic-buck-5kw-v2,
    branched from upstream main which already carries the frozen V1 and the
    Engineering Knowledge System V0.
    - input/requirements.yaml separates the user requirements from the inputs the
    task leaves open; their chosen values will live in design/assumptions.md.
    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
2026-10-10 feat(automation): reusable V2 KiCad pipeline, grid router and ngspice simulation layer
    Add the automation the 5 kW SiC buck needs without touching the V1 tools:
    - kicad_tools/project_schematic.py: parametrised hierarchical schematic and
    project generator (official or generated symbols, PWR_FLAGs, continuation
    sheets, KiCad 10 net classes and netclass patterns, custom .kicad_dru rules,
    deterministic uuid5 ids, connectivity pre-check against the default ERC matrix).
    - kicad_tools/project_footprints.py: footprint availability and pad-number
    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
2026-10-10 design(v2): baseline schema 3 - exposed-tab pad resistance, geometry arithmetic, discontinued heatsink, final verifier corrections
2026-10-10 feat(verification): data-driven V2 layout metrics checker for the SiC buck boards
    automation/verification/check_sic_layout.py measures a routed KiCad board against a
    JSON layout spec: commutation- and gate-loop proxies, Kelvin-source separation
    (KR-PCB-003), per-layer copper-to-copper isolation distances for every net-class pair
    with the baseline thresholds (9.0 mm HV-to-SELV, 5.0 mm HV-to-PE, 3.0/1.0 mm functional
    and inter-island), ISO_BARRIER copper-free strip, slot around-the-end creepage path,
    heatsink keep-out, decoupling distances, sensing Kelvin pairs, ground-plane extent
    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
2026-10-10 feat(v2): design documents, calculations, board models, ERC-clean schematics and simulation campaign
    Design documents (all citing design/design_decisions.json and the knowledge ids they
    rest on): assumptions register (46 rows, U/S/S*/D/H classes), component selection with
    64 component records, reproducible calculations (automation/scripts/calculate_sic_buck.py,
    19 asserted invariants), thermal analysis, knowledge application, architecture and
    option comparison, stack-up, hardware/firmware contract, consistency review.
    Electrical models: sic_buck_power_model.py (237 parts, 101 nets, 8 custom footprints
    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
2026-10-10 design(v2): Magnetic Database record for the custom 272 uH High Flux output choke
2026-10-10 docs(v2): propagate baseline schema 4 (OTP ladder 80/90/100 C, REF3130, fault combiner) and add release tooling
    The lowered heatsink-NTC threshold ladder (CR-25) and the CR-26 fixes are now carried
    through thermal_analysis, assumptions, architecture, component_selection,
    firmware_interface, knowledge_application, pcb_stackup, the architecture comparison,
    the component records (65 records) and the reproducible calculation script, whose
    19 invariants still pass; consistency_review.md records the propagation.
    automation/scripts/verify_sic_buck.py checks, for both boards, that the latest native
    ERC and DRC runs passed with zero findings and still match the delivered files, that
    export manifests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
2026-10-10 review(v2): knowledge utilisation report - 24 decisions traced to skills, rules and references with verification status
2026-10-10 docs: knowledge-base feedback from the V2 run; tests for the two-board verifier
2026-10-10 wip(pcb): control board placed and routed to 39 open connections; power board layout restarted
    Checkpoint of the actual KiCad state, not a finished layout. The control board
    (120 x 80 mm, 4 layers, candidate B of two evaluated floorplans) is fully placed and
    routed except 39 connections on 20 logic/fault nets; native DRC with parity reports
    0 violations, 0 parity findings and 39 unconnected items (verification/drc, nine
    iterations kept as evidence). The independent model/schematic/board netlist check
    matches exactly. The first power-board layout agent terminated without writing any
    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
2026-10-10 fix(pcb): structural DRC sources removed at the schematic level; layout review and stage-3 evidence
    Power project regenerated (ERC 0 findings, run 20261010T165532Z): UCC21710 drivers now use
    an AIPE footprint that carries its own 1.2 x 16.6 mm isolation slot (no library
    silkscreen crossing a board cut-out), the AMC1311 slot is lengthened to 10.8 mm, the
    LED anode nodes of the indicator strings form a PGND_LV class of the PGND reference
    island (0.3 mm to PGND instead of a 3 mm HV spacing an 0805 LED cannot meet), and the
    pin-field exceptions now cover no-connect pads whose unconnected-* nets fall into
    KiCad's Default class. 45 design rules; nothing weakened.
    Also records the independent layo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
2026-10-11 feat(pcb): both V2 boards placed, routed and at native DRC zero; exports, metrics, review and correction pass
    Power board AIPE_SiC_Buck_Power (240 x 180 mm, 4 x 70 um): 237 footprints, 4755 tracks,
    606 vias, 36 zones, router 0 open; kicad-cli DRC --schematic-parity --severity-all
    0 violations / 0 unconnected / 0 parity (verification/drc/20261011T054445Z-drc-d0914d79,
    board sha256 b1bb5698...). Stored zone fills are the rule-aware copper (no-refill DRC
    499 -> 0, engineering_checks/stored_zone_fill_check_power.json).
    Control board AIPE_SiC_Buck_Control (120 x 80 mm, 4 x 35 um): 207 footprints, 5995 tracks,
    798 vias, 20 zones, router 0 open; DRC 0 / 0 / 0 (20261011T051246Z-drc-f801ed3c, sha256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
2026-10-11 docs(v2): design report, known-issues register, knowledge report PCB closure, status, PR body, README
    review/design_report.md (14 sections incl. test points; every number cites its evidence
    file), verification/known_issues.md (49 rows V2-01..V2-49 in four priority groups),
    review/knowledge_utilisation_report.md closes the seven P-marked decisions with the
    measured layout values and adds the PCB-phase rule table (7.1), docs/status-v2.md,
    docs/v2-pull-request.md (prepared PR body), docs/reproduce-v2.md (real generator CLIs
    and regeneration caveats), docs/knowledge-feedback-v2.md (PCB-phase proposals), README
    V2 section. Control-board regeneration check with the current shared router recorded
    (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
2026-10-12 feat(v2.1): 8-direction router with simplification and tangent arcs, routing-quality checker, wired schematic presentation layer
    Router (automation/kicad_tools/grid_router.py, new path_geometry.py): opt-in plan key
    'style' (V2 geometry byte-for-byte when absent) with an 8-direction Grid.astar (octile
    heuristic, parent-direction bend penalties 45/90, both-orthogonal-neighbours corner
    rule), octilinear string pulling, short-run collapse and on-grid 45-degree chamfers
    validated on the occupancy corridor, a final beautify stage (after prune_unused_vias,
    before ground zones) that replaces bends by adaptive-radius tangent PCB_ARC fillets
    with per-chain fallback, per-net smooth_policy (no arcs on p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
2026-10-12 fix(control): deterministic corridor zone order and zone identities; control board rebuilt with identical copper
    island_corridors sorts the stage-2 corridor records by (net, rect, xy, leg) before priorities
    are assigned; zone KIIDs are uuid5 identities ranked so the 12V_PROT / 5V equal-priority
    tie-break (KiCad resolves equal-priority zones by KIID) is fixed in the V2 outcome. A second
    full build reproduces the repository board: zone table 20/20 identical (priorities, KIIDs,
    outlines, filled areas), copper identical item for item, per-net lengths within 0.001 mm.
    Control board DRC 0/0/0 (20261012T114513Z-drc-3461f467, sha 52ca6c23...), routing-quality
    totals unchanged (4262 segments + 261 ar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
2026-10-12 docs(v2.1): V2 vs V2.1 comparison report, known-issues and design-report updates, manufacturing README, status, PR body, architecture
    review/v2_v21_comparison.{md,json} with schematic section clips (review/schematic_sections/) and
    the crop pairs; verification/known_issues.md keeps the 49 V2 rows (15 annotated with V2.1 values)
    and adds V2.1-01..V2.1-18; review/design_report.md V2.1 addendum; manufacturing/README.md rewritten
    for the V2.1 bundles; knowledge_utilisation_report.md addendum (no decision changed); README V2.1
    section; docs/status-v2.1.md; docs/v2.1-pull-request.md; docs/reproduce-v2.md V2.1 section;
    docs/architecture.md V2.1 modules. Each document fact-checked by two independent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
2026-10-13 Correct sensing circuits and add verified V2.2 local bypasses
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2026-10-21 Remediate DAB-V1 routing: fine-pitch row escapes, exit lanes, plane continuity, time-boxed router
    Root causes of the 2026-10-21 DRC failures and open connections of the three DAB-V1 boards are documented in
    docs/dab-10kw/routing-remediation.md; the generator and the grid router were changed accordingly and the boards were
    regenerated and re-verified with kicad-cli 10.0.6 (ERC, DRC --schematic-parity --severity-all --refill-zones, exports,
    netlist equality, copper islands, barrier geometry).
    Results (before -> after): primary 22 DRC errors -> 0, 82 unconnected -> 26; secondary 2 -> 0, 81 -> 23;
    control not routed (499) -> routed, 0 errors, 24 unconnected. ERC 0 and parity 0 on all boards. Op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
2026-10-21 ci: use a block scalar for the KiCad detection step
    The plain-scalar `run:` value contained ": " ("kicad-cli not found: KiCad-dependent ..."), which is invalid YAML; GitHub
    rejected the workflow file at start-up (run 39598747281 on the fork failed with no jobs). No test or check was changed.
2026-10-21 build: declare scipy in the test extra (copper-path and sheet-resistance analyses)
    The host-test workflow failed at collection on Linux: tests/test_copper_paths.py and tests/test_sheet_resistance.py import
    automation.kicad_tools.copper_paths / sheet_resistance, which need scipy.sparse. The dependency was present on the
    development host but not declared. New optional extra `analysis`; `test` includes it.
2026-10-21 tests: resolve recorded evidence paths against the repository
    routing_progress_{control,power}.json and the DRC manifests store the absolute path of the machine that produced them
    (D:\Cursor Workspace\AIPE-PCB-Agent\...). The control-board evidence test asserted that path and therefore failed on
    every other checkout (CI: 1 failed); the power-board test skipped silently. Both now resolve a recorded path by its
    repository-relative tail when the recorded absolute path does not exist, and still compare the recorded SHA-256 with the
    committed board, so the evidence is verified on CI instead of skipped. The committed boards match the recorded hashes.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
